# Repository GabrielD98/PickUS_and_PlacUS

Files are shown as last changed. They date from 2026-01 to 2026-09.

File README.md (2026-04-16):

# PickUS and PlacUS

A 4-axis (X, Y, Z, Yaw) PCB pick-and-place machine for automated SMD component assembly. Built for the S4 robotics project at Université de Sherbrooke.

## Table of Contents

1. [About](#about)
2. [Features](#features)
3. [Tech Stack](#tech-stack)
4. [Project Structure](#project-structure)
5. [Quick Start](#quick-start)
6. [Roadmap](#roadmap)
7. [Contributing](#contributing)
8. [License](#license)
9. [Contact](#contact)

---

## About

### Problem
Manual SMD component placement onto PCBs is time-consuming and error-prone. Small labs and educational institutions need an affordable pick-and-place machine for fast prototyping.

### Solution
PickUS and PlacUS is an open-source, 4-axis automated pick-and-place machine that:
- Picks SMD components using a vacuum pump system
- Places them onto PCBs with positional accuracy
- Uses stepper motors for precise X, Y, Z, and rotational (Yaw) control
- Integrates with KiCad placement files for automated workflows

### Audience
Ideal for robotics project teams, PCB assembly labs, and makers who need to automate component placement without high capital investment.

---

## Features

- **4-Axis Control**: X, Y, Z positioning + Yaw rotation for flexible placement
- **Vacuum Pick System**: Pneumatic pump and valve for reliable component pickup
- **Pressure Sensing**: Real-time feedback to detect successful component pickup
- **End-Stop Protection**: Z-axis limit switch to prevent collision damage
- **ESP32-S3 Controller**: Over-the-air updateable firmware with multiple I/O options
- **Python HMI**: Cross-platform graphical interface for machine control
- **KiCad Integration**: Direct import of `.pos` placement files for batch production
- **Modular Design**: Separate electrical, firmware, and HMI components

---

## Tech Stack

| Component | Technology |
|---|---|
| Microcontroller | ESP32-S3 (32-bit, dual-core, 240 MHz) |
| Motor Control | Stepper drivers (NEMA-17 steppers on X,Y,Z and NEMA_8 on YAW) |
| Firmware | C++ with PlatformIO / Arduino framework |
| Motor Library | [AccelStepper](https://github.com/waspinator/AccelStepper) |
| Communication | UART (serial) at 115200 baud |
| HMI | Python 3 + PyQt5/PySimpleGUI |
| Serial Library | `pyserial` |
| PCB Design | KiCad 8+ |
| Schematic | `circuitPNP/` main board + `PCB_test/` test board |

---

## Project Structure

```
PickUS_and_PlacUS/
├── Electrical/              # KiCad schematics and PCB layouts
│   ├── PNP_MOBO_V1/         # Main control board
│   ├── PNP_TEST_CIRCUIT_V1/ # Test board for validation
│   └── README.md            # Electrical recreation guide
├── Firmware_esp32/          # ESP32-S3 firmware (PlatformIO)
│   ├── src/                 # C++ source files
│   ├── lib/                 # Libraries (AccelStepper, etc.)
│   ├── test/                # Unit tests
│   ├── include/             # Header files
│   └── platformio.ini       # PlatformIO config
└── HMI/                     # Python host interface
    ├── src/                 # Main HMI modules
    │   ├── gui/             # GUI components
    │   ├── communication.py # Serial protocol
    │   ├── controller.py    # Command orchestration
    │   ├── main.py          # Entry point
    │   └── ...
    └── tests/               # Unit and integration tests
```

---

## Quick Start

Each subsystem has its own detailed README:

- **[Firmware_esp32/](Firmware_esp32/)** — ESP32-S3 firmware setup and configuration
- **[HMI/](HMI/)** — Python host interface installation and usage
- **[Electrical/](Electrical/)** — PCB design and electrical recreation guide
- **[Mechanical/](Mechanical/)** — Mechanical recreation guide, BOM, and STL

---

## Getting Started

### For Developers

1. Clone this repository
2. Navigate to the subsystem folder of interest (Firmware, HMI, or Electrical)
3. Follow the README in that folder for detailed setup instructions

### Project Overview

| Subsystem | Technology | Purpose |
|---|---|---|
| **Firmware_esp32** | C++ with PlatformIO | Real-time motor control, sensor reading, and command execution |
| **HMI** | Python 3 + PyQt5 | Cross-platform UI for machine operation and KiCad file import |
| **Electrical** | KiCad 8+ | Circuit design and PCB layouts |

---

## Roadmap

- [ ] Multi-head support for parallel placement
- [ ] Vision-based component alignment
- [ ] Auto feeder implementation
- [ ] Machine learning for optimal pick order optimization

---

## License

This project uses a split-license model:

- **Software (firmware + HMI source code)**: MIT License ([LICENSE](LICENSE))
- **Hardware design files** (schematics, PCB layouts, fabrication files): CERN Open Hardware Licence v2 - Permissive ([LICENSE-HARDWARE](LICENSE-HARDWARE))

---

## Acknowledgments

- [PlatformIO](https://platformio.org/) for embedded development tools
- [KiCad](https://www.kicad.org/) for PCB design
- [AccelStepper Library](https://www.airspayce.com/mikem/arduino/AccelStepper/) for motor control
- Université de Sherbrooke robotics program
- All contributors and testers

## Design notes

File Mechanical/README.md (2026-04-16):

# Mechanical instructions

The Pick and place is built in a specific way with complex pieces, to insure a good functionning device, please follow the instructions provided.

## Bill of Material

The project is made with pieces and component purchased on the internet. Including alluminum extrusion, gears, belts, rails and motors. But a big part of the project can be 3d printed and laser cutted. 

### Pieces to Print or Laser cut

All the STL files needed are provided in the Mechanical folder in a folder named STL_Files. We recommend to print all the pieces before starting the assembly, but the pieces needed in each instruction will be cited so can be printed in order. All the pieces are printed with PLA for reduced costs.

There is also a MakerWord project created with all the pieces ready to print. https://makerworld.com/en/models/2670527-pickus-and-plackus#profileId-2955730

The base plate is laser cutted for a size reason and is made of wood.

### Pieces to Buy

All the pieces or component to buy are in the Mechanical folder named BOM. The Bill of Material contain all the pieces needed to complete de Project with links to the websites. Please note that the product were purchased and delivered in Canada so some of the links may not work or be discontinued.

The pieces were bought principally on Amazon.ca and Aliexpress.com. 

## Instructions

The complete assembly is provided in the STL_Files folder to guide you during the assembly process.

### Step 1 : Base

#### Pieces needed: 
1. Alluminum extrusion 7x
#### Print Needed:
1. FootMountSS-BackRight.stl
2. FootMountSS-FrontRight.stl
3. FootMountSS-BackLeft.stl
4. FootMountSS-FrontLeft.stl
5. 90DegreesJoint.stl 2x
6. BasePlateSupport.stl (Laser Cutted)
7. BasePlate.stl (Laser Cutted)

Please Note: Always place the T-nuts needed in the extrusions before assembling.

First, Install the two 90 degrees joint in the middle of two alluminum extrusions. These will be on the front and back. Then, build a square with the four foot mounts, make sure to place them at the right place. Place the fifth extrusion in the middle and install the BasePlateSupport. Secure it in the four corners and then place the two remaining extrusions on the two sides. 

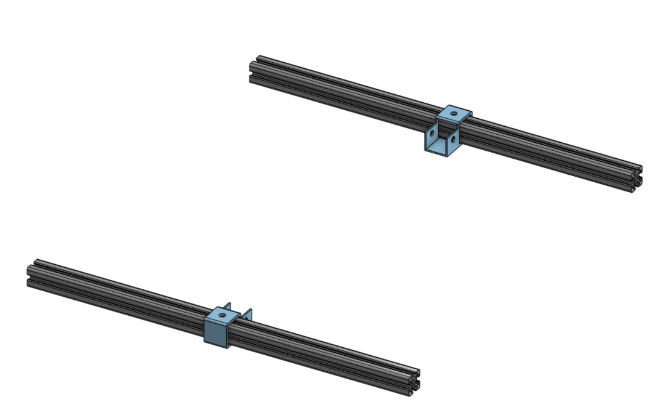
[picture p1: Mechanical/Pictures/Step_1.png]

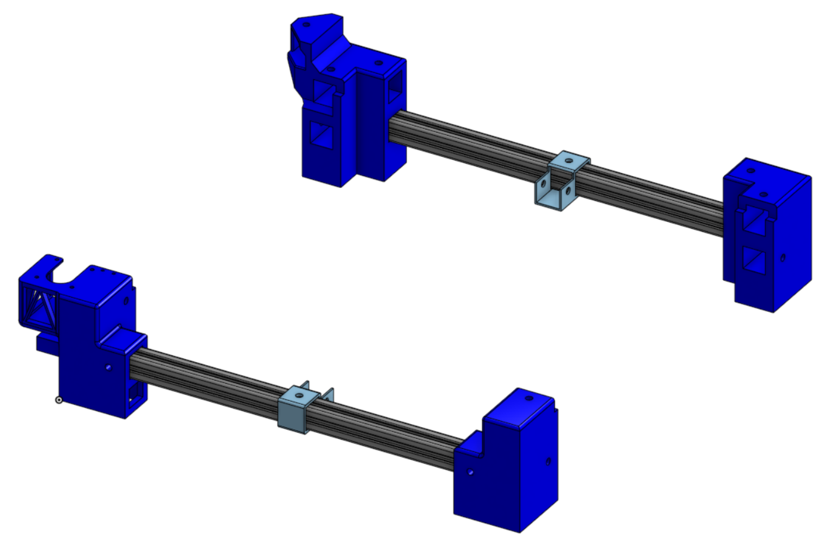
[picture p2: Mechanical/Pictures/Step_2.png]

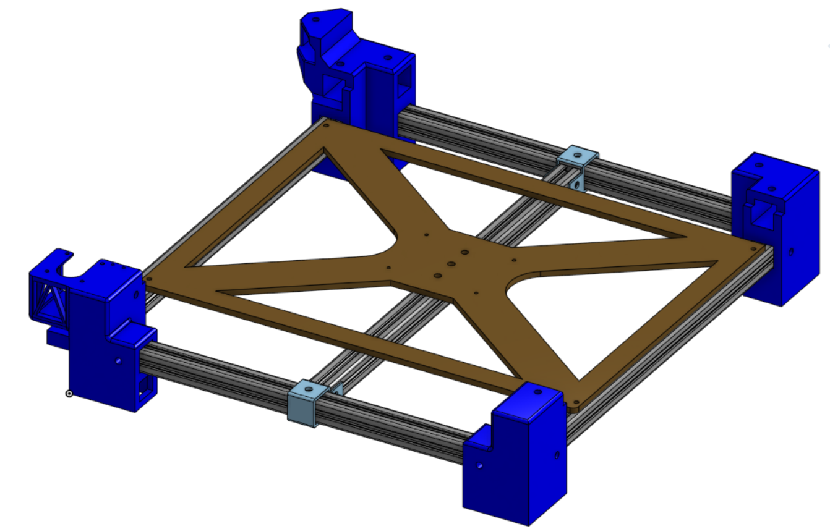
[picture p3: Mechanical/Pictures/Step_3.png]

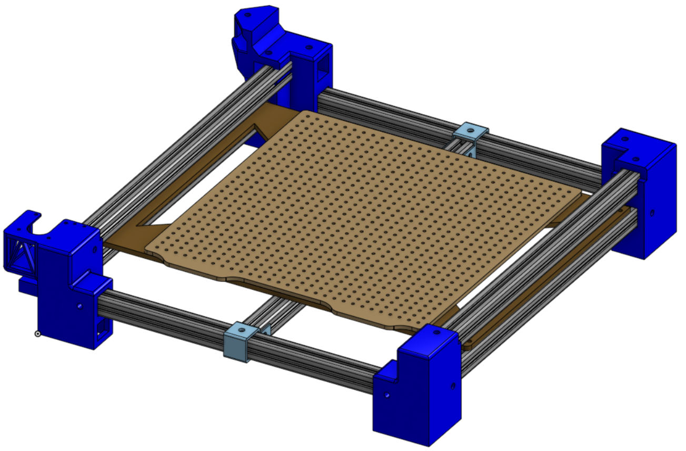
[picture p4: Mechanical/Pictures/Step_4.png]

---
### Step 2 : Y Movement

#### Pieces needed: 
1. Linear rails 2x
2. Gear 2x
3. Timing belt
4. Timing Belt Fixing Piece
5. Heat insert M4
6. Nema 17 motor
#### Print Needed:
1. Adaptor_RailY_Extrude_Inferior.stl 2x

Install the two rails with M3 bolts and Tnuts on the top extrusions. Place a heat insert in one of the printed piece and fix it to the moving cart on the left side, heat insert in the direction of the exterior of the device. Fix the other one on the opposite side. Place the gears, one on the motor, one with a M5 nut and bolt on the back left footmount. Cut the timing belt at the length needed, install on the gears but dont install now the motor. Put each extrimity of the belt on the fixing piece and then screw it in the heat insert. Now, install the motor in the front left foot mount. If the belt is too loose, you can cut it a little bit to have good belt tension. The gear on the motor must be scewed on the shaft and the other one left loose.

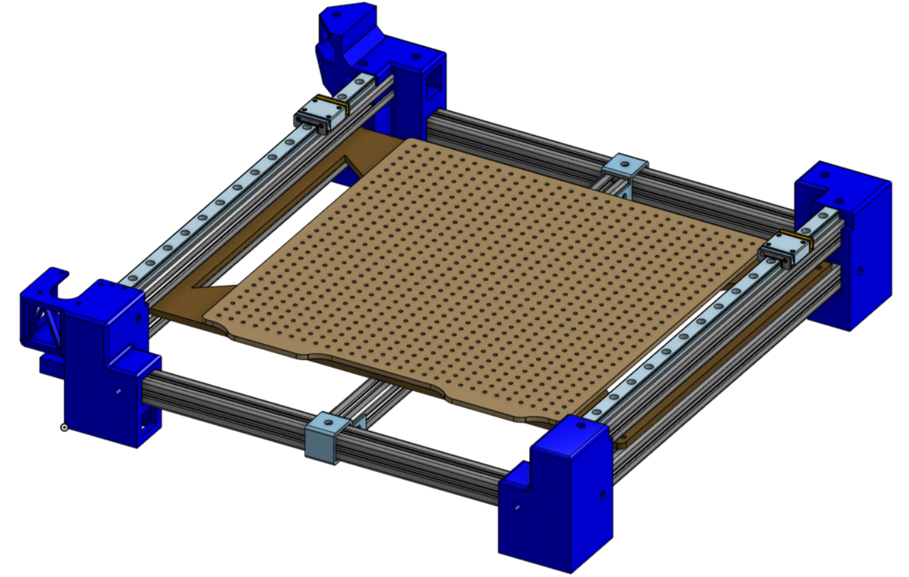
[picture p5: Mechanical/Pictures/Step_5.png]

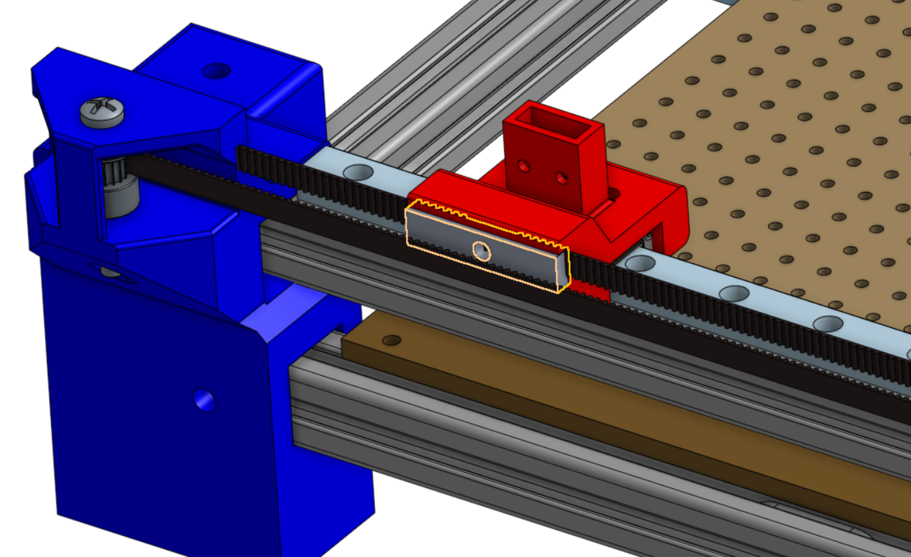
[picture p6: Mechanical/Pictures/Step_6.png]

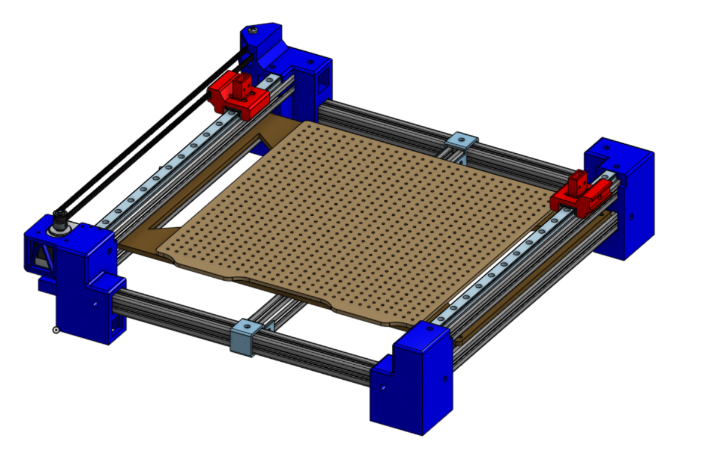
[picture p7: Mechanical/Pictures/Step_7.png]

---
### Step 3 : X Movement

#### Pieces needed: 
1. Linear rails 1x
2. Gear 2x
3. Timing belt
4. Timing Belt Fixing Piece
5. Heat insert M4
6. Nema 17 motor
7. alluminum extrusion
#### Print Needed:
1. Adaptor_RailY_Superior_Motor.stl
2. Adaptor_RailY_Extrude_Superior_Idle.stl
3. PnPHead.stl

Put the two complement on the rails. Big one on the motor side. Put a heat insert on the back of the PnP Head. Place the extrusion with a linear rail on the side facing the front. Screw the PnP head on the cart. Install the gears and timing belt as done in step 2 but install the motor first. 

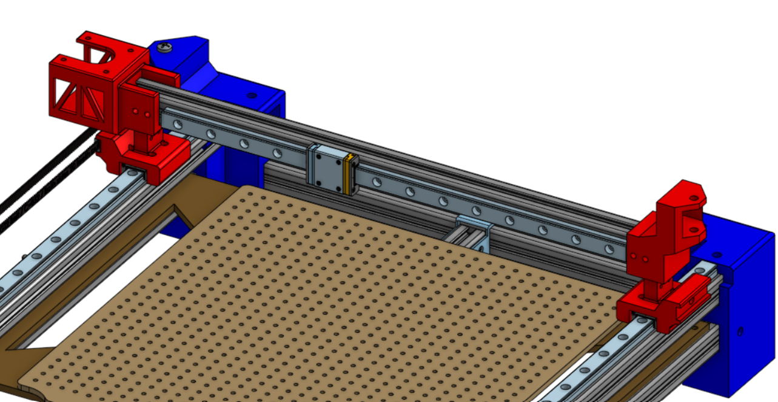
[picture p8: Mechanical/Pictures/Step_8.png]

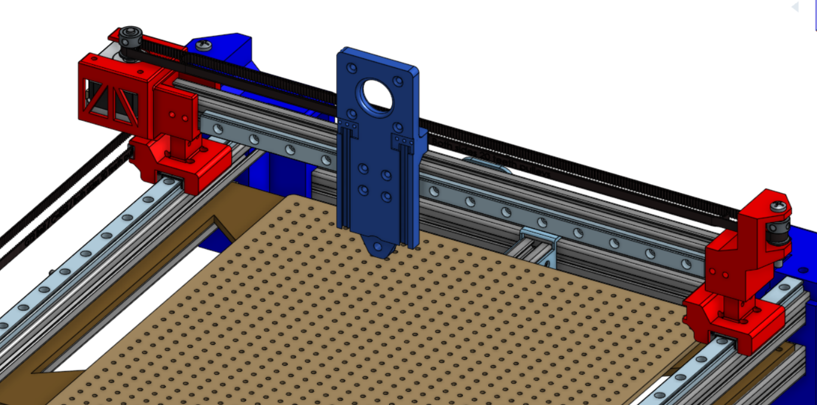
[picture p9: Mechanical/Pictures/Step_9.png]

---
### Step 4 : Z Movement and yaw

#### Pieces needed: 
1. Gear 2x
2. Timing belt
3. Timing Belt Fixing Piece
4. Heat insert M4
5. Nema 17 motor (small)
6. Nema 8 motor + toolhead
#### Print Needed:
1. PnPPicker.stl

Put a heat insert on the hole on the side of the PnP Picker piece. Install the Nema 8 motor and nozzle on the PnP Picker piece. Install the small Nema 17 motor on top of the PnP Head. Insert the Picker into the Head left rail. Then, install the gears and timing belt. 

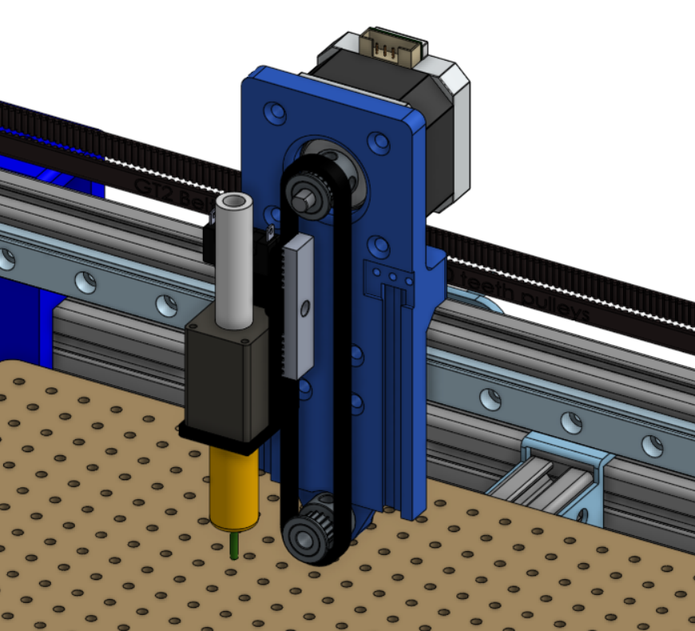
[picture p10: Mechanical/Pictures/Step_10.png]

---
### Step 5 : Limit Switch, cable management, cable chain and (electric box (peut être dans une autre étape))

#### Pieces needed: 
1. Heat insert M4 x4
2. Cables
3. Limit Switch x3
4. Electric components
#### Print Needed:
1. Chain_Adaptor_1.stl
2. Chain_adaptor_2.stl
3. Chain_Adaptor_3.stl
4. Chain_Adaptor_4.stl
5. Chain_Link.stl x25
6. Chain_Cover.stl x 20
7. Chain_Support_TRail_YAxis.stl x3
8. Electric_Box.stl

It is now time to put all the cables and the XYZ limit switches. Make sure to cut long enough wires for it to pass trough the cable chains (if you want to install some). You can put all the electrics (PCB, Vacuum, drives) in the electric box underneath the PnP. 

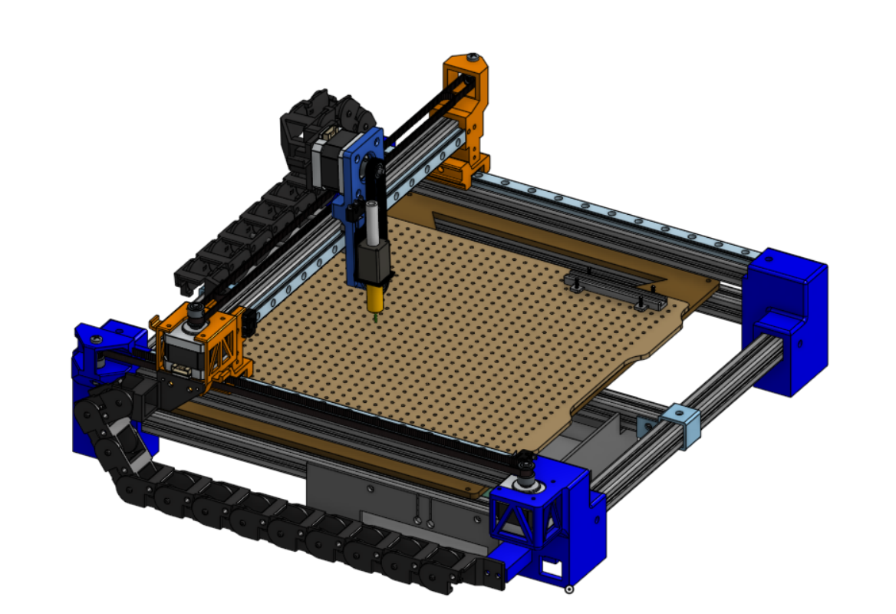
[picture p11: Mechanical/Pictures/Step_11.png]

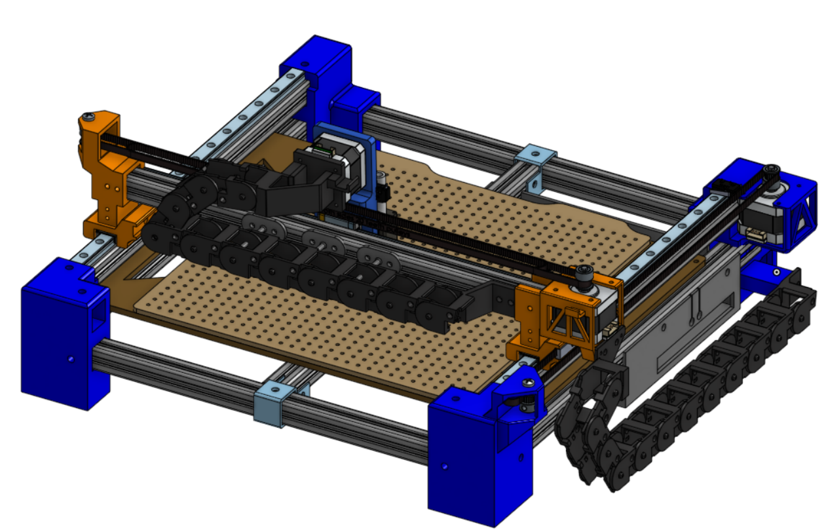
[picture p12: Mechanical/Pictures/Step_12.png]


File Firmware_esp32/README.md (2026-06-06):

# Firmware (ESP32-S3)

Firmware for motor control, sensor reading, and command execution on the PickUS and PlacUS machine.

## Prerequisites

- [PlatformIO](https://platformio.org/) (VS Code extension recommended)
- ESP32-S3 DevKitC-1 board
- USB-to-Serial cable for flashing

## Installation

1. **Install PlatformIO**
   - Open VS Code and install the PlatformIO extension

2. **Open the project**
   ```bash
   cd Firmware_esp32
   ```

3. **Build and upload**
   ```bash
   pio run --target upload
   ```

4. **Monitor serial output** (115200 baud)
   ```bash
   pio device monitor
   ```

---

## Configuration

### Pin Mapping (`boardconfig.h`)

| Signal | Pin | Direction |
|---|-----|---|
| Motor X DIR/STEP/EN | 6 / 7 / 15 | Output |
| Motor Y DIR/STEP/EN | 16 / 17 / 18 | Output |
| Motor Z DIR/STEP/EN | 3 / 46 / 11 | Output |
| Motor YAW DIR/STEP/EN | 12 / 13 / 14 | Output |
| Vacuum pump | 5 | Output |
| Valve | 4 | Output |
| Limit switch X | 35 | Input |
| Limit switch Y | 36 | Input |
| Limit switch Z | 37 | Input |
| Pressure sensor CLK/DATA | 2 / 1 | I/O |
| CAN TX/RX | 47 / 48 | I/O |

### Serial Communication

- **Baud Rate**: 115200
- **Protocol**: Command-based (see Command IDs below)
- **Flow Control**: None

---

## Usage

### Firmware Overview

The firmware consists of these key modules:

| Module | File | Responsibility |
|---|---|---|
| `Controller` | `controller.h/cpp` | Coordinates command handling, motion, homing, pick/place sequences, and machine state updates |
| `DataModel` | `datamodel.h/cpp` | Thread-safe shared command/position/state buffer between the controller and the communication task |
| `Communication` | `main.cpp` | UART protocol that receives `command_t` packets and sends back `statusFrame_t` replies |
| `Geometry` | `geometry.h/cpp` | Converts between cartesian coordinates and motor steps / velocities |
| `Mosfet` | `mosfet.h/cpp` | Controls the vacuum pump and valve outputs |
| `Pressure Sensor` | `pressuresensor.h/cpp` | Reads and converts the bit-banged pressure sensor signal into kPa |
| `Limit Switch` | `limitswitch.h/cpp` | Monitors X, Y, Z end-stops for homing and safety |

### Command IDs

| Command | Value | Description | Parameters |
|---|---|---|---|
| `STOP` | 0 | Stop all motors | None |
| `MOVE` | 1 | Move to position at velocity | x, y, z, yaw, velocity |
| `PICK` | 2 | Pick sequence (lower Z, activate pump) | None |
| `PLACE` | 3 | Place sequence (activate valve) | None |
| `HOME` | 4 | Run homing sequence | None |
| `EMPTY` | 5 | No-op / idle | None |

### Machine States

| State | Description |
|---|---|
| `READY` | Idle, waiting for a command |
| `MOVING` | Executing a MOVE command |
| `PICKING` | Executing a PICK sequence |
| `PLACING` | Executing a PLACE sequence |
| `HOMING` | Executing the homing sequence |
| `ERROR` | Fault condition detected |

---

## Testing

### Run Unit Tests

The firmware includes test hooks controlled by `platformio.ini` build flags:

- `ENABLE_TEST=1` runs the internal test task instead of normal control/communication tasks.
- `ENABLE_COM_TEST=1` runs the communication test task alongside the test task.
- Both flags are set to `0` by default for normal firmware operation.

---

## Project Structure

```
Firmware_esp32/
├── src/                     # Firmware source files
│   ├── boardconfig.h
│   ├── controller.cpp/h
│   ├── datamodel.cpp/h
│   ├── geometry.cpp/h
│   ├── limitswitch.cpp/h
│   ├── main.cpp
│   ├── mosfet.cpp/h
│   ├── pressuresensor.cpp/h
│   └── tests/               # Internal test helpers and scenarios
├── lib/                     # Shared data types and external libraries
│   ├── data.hpp
│   └── AccelStepper/
├── include/                 # Header includes placeholder
├── output/                  # Generated build/output artifacts
├── test/                    # PlatformIO test entry point
│   └── README
├── platformio.ini           # PlatformIO configuration
└── README.md
```

---

## Dependencies

- [AccelStepper](https://github.com/waspinator/AccelStepper) (`waspinator/AccelStepper@^1.64`) — stepper motor control

---

## Troubleshooting

### Serial Monitor Not Connecting
- Verify USB cable is connected
- Check Device Manager (Windows) or `/dev/ttyUSB*` (Linux) for the correct COM port
- Ensure baud rate is set to 115200

### Build Fails
- Clean the build: `pio run --target clean`
- Check that all libraries are installed and up to date

---

## Next Steps

- See [main README](../README.md) for project overview
- See [HMI README](../HMI/) for host interface setup
- See [Electrical README](../Electrical/) for hardware design
- See [Mechanical README](../Mechanical/) for mechanical design

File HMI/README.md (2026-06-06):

# HMI (Python Host Interface)

Cross-platform graphical interface for controlling the PickUS and PlacUS machine. Communicate with the ESP32 firmware over USB serial, import KiCad placement files, and orchestrate pick-and-place operations.

## Prerequisites

- Python 3.8 or higher
- `pip` package manager
- USB connection to ESP32-S3 board

## Installation

1. **Install dependencies**
   ```bash
   pip install pyserial
   ```

2. **Navigate to HMI source folder**
   ```bash
   cd HMI/src
   ```

3. **Run the HMI**
   ```bash
   python main.py
   ```

---

## Configuration

### Serial Port Settings

To find your port:
- **Windows**: Device Manager → Ports (COM & LPT)
- **Linux**: Run `ls /dev/ttyUSB*`
- **macOS**: Run `ls /dev/tty.usbserial*`

---

## Usage

### Typical Workflow

1. Launch the HMI: `python main.py`
2. Load a KiCad `.pos` file via the GUI
3. Home the machine to access manual mode
4. Configure component feeders for each tray
   1. Fill all of the required fields in the displayed window
   2. Place the tip of the gripper on the first piece of the storage
   3. Confirm to save the data 
5. Calibrate PCB position
   1. place the tip of the gripper on the calibration point of the PCB (has to be set by the user in KiCad)
   2. Confirm to save the data 
6. Generate commands by clicking the slice button
5. Start the pick-and-place cycle
6. Monitor progress and pause/resume as needed

### HMI Module Overview

| Module | Responsibility |
|---|---|
| `Controller` | Manages state, command queue, and background control loop |
| `CommandDispatcher` | Queues commands and serializes them for transport |
| `PnPStateMachine` | Resolves controller state transitions and next commands |
| `MachineTelemetryDecoder` | Decodes telemetry packets from the ESP32 |
| `HomingService` | Runs the homing workflow in a background thread |
| `Communication` | Low-level UART wrapper around `pyserial` |
| `FileInterpreter` | Parses KiCad `.pos` placement files into `Piece` objects |
| `Slicer` | Generates ordered `Command` sequence: pick → move → place per component |
| `Storage` | Tracks available components in feeder trays |

---

## Testing

### Run All Tests

```bash
cd HMI/tests
python run_test.py
```

### Individual Test Files

- `test_controller_communication.py` — Serial protocol tests
- `test_file_interpreter.py` — KiCad `.pos` file parsing
- `test_slicer.py` — Command sequence generation
- `test_storage.py` — Feeder tray logic

Each test file can be run independently:

```bash
python test_file_interpreter.py
```

---

## Project Structure

```
HMI/
├── src/                     # Main HMI modules
│   ├── main.py              # Entry point
│   ├── communication.py      # Serial protocol
│   ├── controller.py         # Command orchestration
│   ├── command_dispatcher.py # Controller command queue management
│   ├── data.py              # Data models
│   ├── file_interpreter.py  # KiCad .pos parser
│   ├── homing_service.py    # Homing workflow
│   ├── machine_telemetry_decoder.py # Telemetry packet decoding
│   ├── slicer.py            # Command generation
│   ├── pnp_state_machine.py  # Controller state transitions
│   ├── storage.py           # Component inventory
│   ├── utils.py             # Utilities
│   └── gui/                 # GUI components
│       ├── interface.py
│       ├── command_widget.py
│       ├── jog_widget.py
│       ├── pnp_state_widget.py
│       └── ...
├── tests/                   # Unit and integration tests
│   ├── run_test.py          # Test runner
│   ├── test_*.py            # Individual test modules
│   └── data/                # Test data files
├── data/                    # Sample data files
└── README.md
```

---

## Class Diagram
### Main project UML
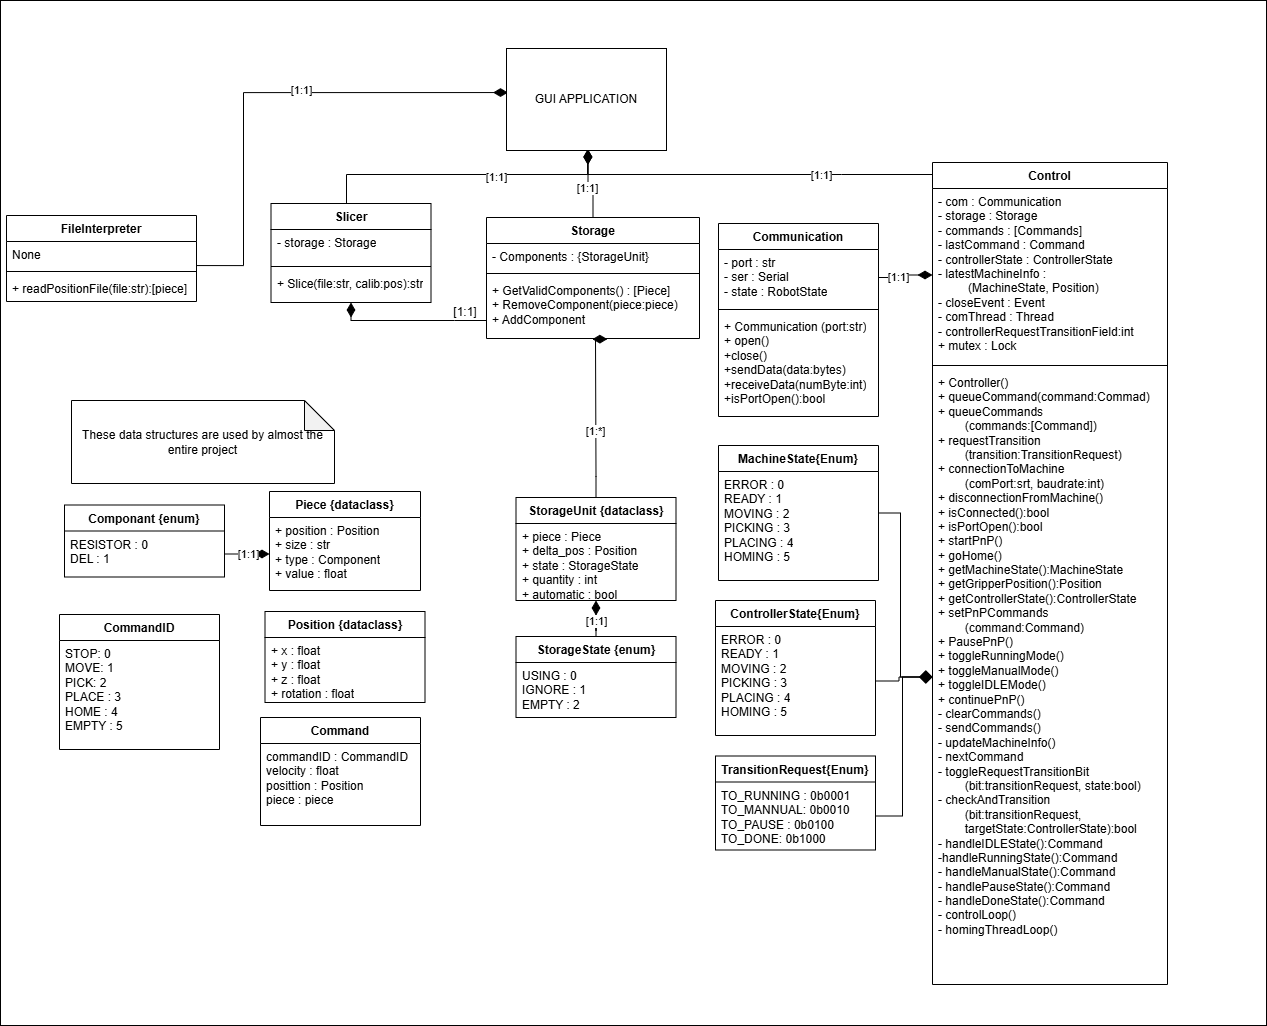
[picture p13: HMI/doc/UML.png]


### GUI UML
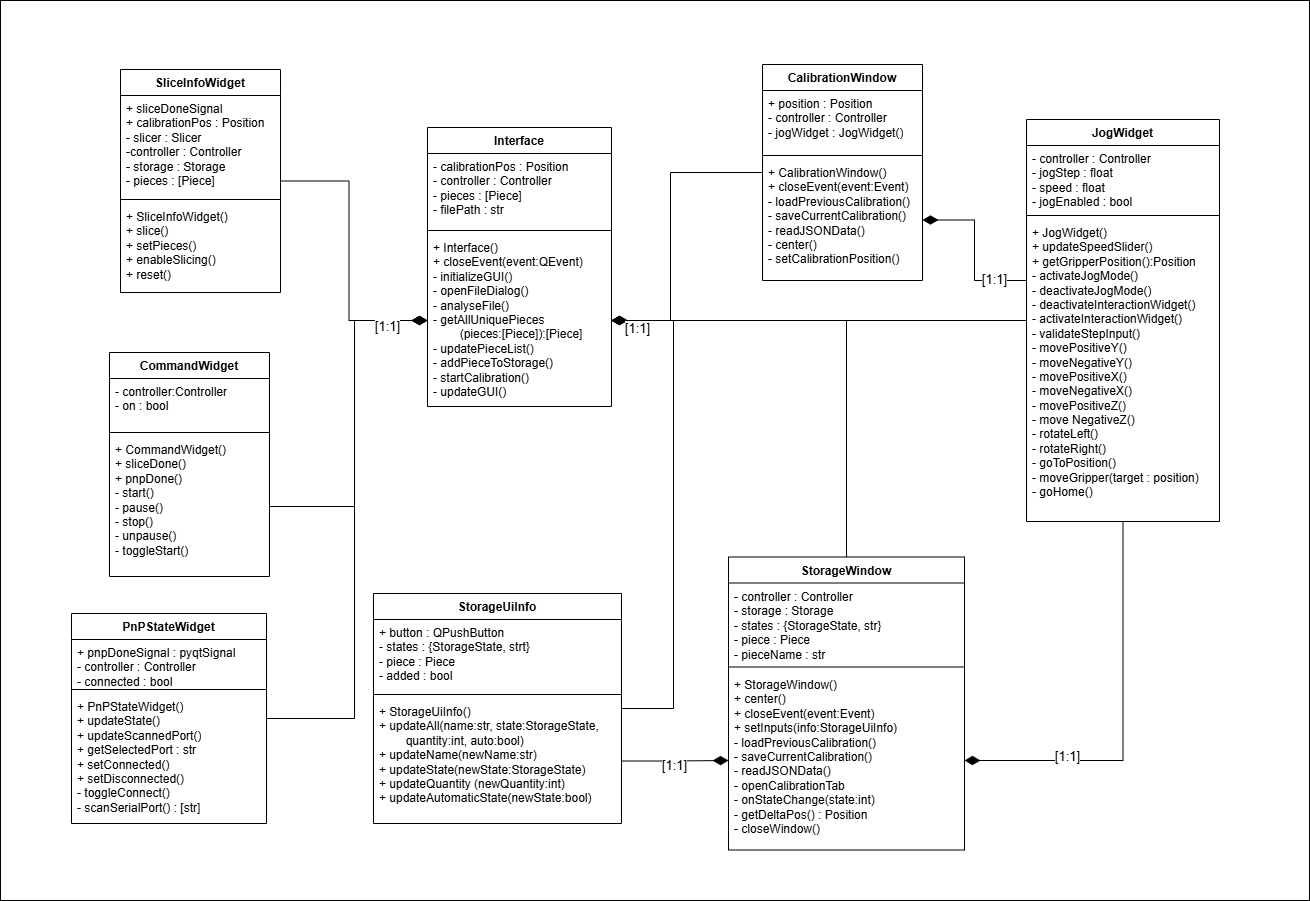
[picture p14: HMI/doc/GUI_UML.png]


---

## Dependencies

- `pyserial` — serial communication with ESP32

---

## Troubleshooting

### Cannot Connect to Serial Port
- Verify the ESP32 is plugged in and connected
- Check Device Manager for the correct COM port
- Ensure no other application is using the port
- Try unplugging and replugging the USB cable

### FileNotFoundError: Cannot find .pos file
- Ensure the full path to the KiCad placement file is correct
- Verify the file exists and is readable

### Commands Not Executing
- Check that the ESP32 firmware is running and responsive
- Open serial monitor to verify communication: `pio device monitor` (in Firmware_esp32 folder)
- Verify baud rate matches (115200)

---

## Next Steps

- See [main README](../README.md) for project overview
- See [Firmware README](../Firmware_esp32/) for ESP32 setup and configuration
- See [Electrical README](../Electrical/) for hardware design
- See [Mechanical README](../Mechanical/) for mechanical design

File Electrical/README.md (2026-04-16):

# Electrical Guide

PCB design and schematics for the PickUS and PlacUS machine. Includes main control board and test board for validation.

## Scope

The electrical work is split into two KiCad projects:

- `PNP_MOBO_V1/` — Main control board for the machine
- `PNP_TEST_CIRCUIT_V1/` — Test board for validating pick and place operation

## Prerequisites

- KiCad 8 (recommended)
- Basic soldering tools and bench power supply for bring-up
- Optional for production:
  - PCB manufacturer account (JLCPCB, PCBWay, etc.)
  - Assembly service for SMT components

---

## Installation & Setup

1. **Install KiCad**
   - Download from [https://www.kicad.org/](https://www.kicad.org/)
   - Install version 8 or later

2. **Open a project**
   ```bash
   cd Electrical/circuitPNP
   ```
   Or for the test board:
   ```bash
   cd Electrical/PCB_test
   ```

3. **Open in KiCad**
   - Double-click the `.kicad_pro` file, or
   - Launch KiCad and open the project file

---

## Project Structure

```
Electrical/
├── PNP_MOBO_V1/
│   ├── PNP_MOBO_V1.kicad_sch      # Main board schematic
│   ├── PNP_MOBO_V1.kicad_pcb      # Main board PCB layout
│   ├── PNP_MOBO_V1.kicad_pro      # Project file
│   ├── fabricationFile.zip       # Gerber, drill, and BOM exports
│   └── bom/                      # Bill of materials
├── PNP_TEST_CIRCUIT_V1/
|   ├── STENCIL.3mf
│   ├── PNP_TEST_CIRCUIT_V1.kicad_sch        # Test board schematic
│   ├── PNP_TEST_CIRCUIT_V1.kicad_pcb        # Test board PCB layout
│   └── PNP_TEST_CIRCUIT_V1.kicad_pro        # Project file
└── README.md
```

---

## Main Board (`PNP_MOBO_V1`)

### Key Subsystems

- **ESP32 Control & Communication**: Control and USB serial lines
- **Stepper Driver Interfaces**: DIR/STEP/EN signals for X, Y, Z, YAW motors
- **Vacuum Pump & Valve Switching**: Power control for pickup system
- **Pressure Sensor Interface**: Two-wire clock+data interface (bit-banged): toggle clock, sensor outputs one data bit per pulse (used for grip detection)
- **End-Stop Connectors**: Limit switch inputs for X, Y, Z axes
- **Can/I2C Connectors**: Additional expansion headers

---

## Test Board (`PNP_TEST_CIRCUIT_V1`)

### Purpose

Validate the pick-and-place workflow with a dedicated test board featuring standard footprints.

---

## Bring-Up & Validation

Complete this checklist as you recreate each board:

- [ ] KiCad project opens without missing symbol/footprint errors
- [ ] ERC passes with no critical errors
- [ ] All connectors have clear pin naming in schematic and silkscreen
- [ ] DRC passes with no critical errors
- [ ] Gerber and drill files exported
- [ ] BOM exported and validated with available stock
- [ ] Board assembled and visually inspected
- [ ] Continuity test completed on power rails and critical nets
- [ ] First power-on done with current-limited supply (no shorts)
- [ ] ESP32 and peripherals communication validated via firmware
- [ ] Motors, pump/valve, and sensors verified functionally

---

## Versioning & Release

- Use a version tag in the board title block and filenames (e.g., `v1`, `v2`)
- Commit schematic and PCB changes together

---

## BOM Organization

Recommended workflow:

- **PCB parts:** use the KiCad interactive BOM export (`PNP_MOBO_V1/bom/ibom.html`)
- **All non-PCB parts (electrical + mechanical):** see [Mechanical BOM](../Mechanical)

## Fabrication Tools

- **For stencil generation:** we use [gerber_to_scad](https://github.com/kirberich/gerber_to_scad)
- **Purpose:** generate stencil or fabrication geometry from the PCB source files

---

## Troubleshooting

### Missing Symbols or Footprints
- Verify all library paths are configured in KiCad
- Check that custom symbols/footprints are in the project library directory

### ERC or DRC Errors
- Review each error and determine if it's a genuine violation or a false positive
- Suppress false positives only after verification

### Design Rule Violations
- Consult your PCB manufacturer's design rules for clearance, trace width, and via sizes
- Update KiCad design rules to match your manufacturer specifications

---

## Next Steps

- See [main README](../README.md) for project overview
- See [Firmware README](../Firmware_esp32/) for ESP32 setup and firmware details
- See [HMI README](../HMI/) for host interface setup
- See [Mechanical README](../Mechanical/) for mechanical design

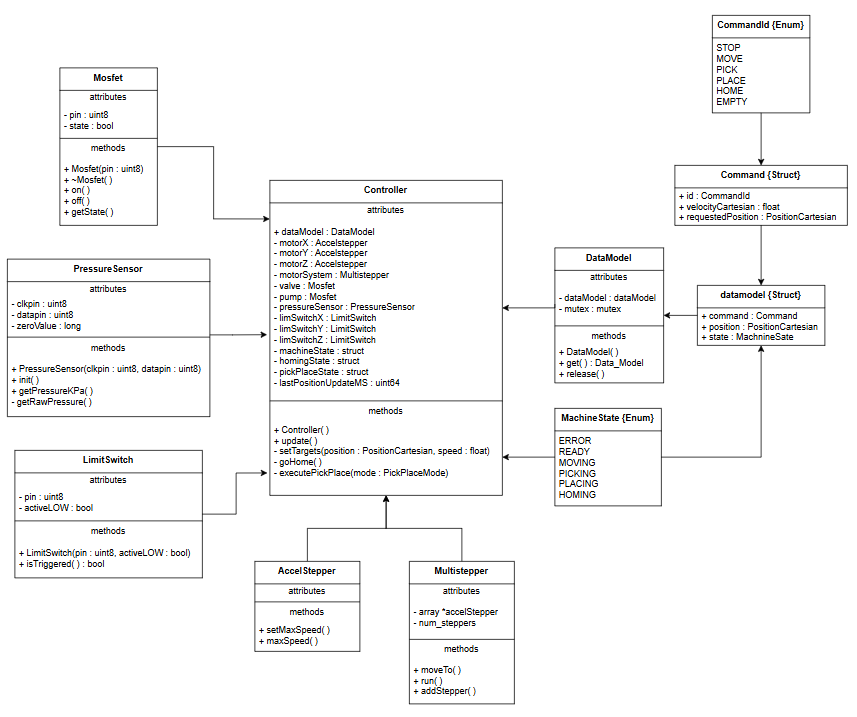
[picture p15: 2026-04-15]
Firmware_esp32/doc/ClassDiagram.png

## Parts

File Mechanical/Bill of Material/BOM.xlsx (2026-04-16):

Name | Quantity | Unitary price (CA$) | Description
17HS4023 NEMA 17 42x42x24mm 0.7A Bi-Polar Dual Phase 1.8° Stepper Motor | 1 | 21.92 | Z-axis motor | https://abra-electronics.com/electromechanical/motors/stepper-motors/nema-17/mot-17hs4023-17hs4023-nema-17-43mm-1.8a-dual-phase-stepper-motor-1.8.html
17HS3401 NEMA 17 42x42x34mm 1.3A Bi-Polar Dual Phase 1.8° Stepper Motor | 2 | 24.23 | X and Y-axis motors | https://a.co/d/0aSwmYSM
SMT head motor NEMA 8 with Nozzle and Air connector JUKI503 nozzle and KSH04-M5 | 1 | 59.07 | Yaw motor and nozzle | https://www.aliexpress.com/item/1005004594670502.html?mp=1
ESP32-S3 | 1 | 14.85 | Microcontroller | https://www.amazon.ca/ESP32-S3-core-board-N16R8-ESP32S3/dp/B0CB8MZKKB?mcid=05db73d0765e36c8a3a28b7daf04915a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
2/3Pin NO/NC Mini Limit Switch 5A 250VAC KW11-3Z-B | 3 | 0.35 | Limit switch | https://www.aliexpress.com/item/1005006085607858.html?curPageLogUid=sMc8UN0EK2FN
6 mm GT2 Pulley 20 Teeth 5mm bore | 6 | 1.74 | Belts gears | https://www.aliexpress.com/item/1005010636842055.html?mp=1
DC 12V Micro Vacuum Pump Mini 370 | 1 | 10.6 | Vacuum pump | https://a.co/d/05owCNzp
DC 3.3V 5V 0-40KPa Digital Barometric Air Pressure Module Connect 2.5mm Soft Tube | 1 | 2.74 | Pressure sensor | https://www.aliexpress.com/item/1005009068730991.html?curPageLogUid=HzYBfmJkU2Bq
DC 3V 3.7V 5V 2-way 2-position Small Mini Electric Solenoid Valve Normally Open | 1 | 4.33 | Solenoid valve | https://www.aliexpress.com/item/1005005779605656.html?mp=1
Miniature Linear Rail Slide With Carriage MGN9H 350 mm | 3 | 23.44 | Rail and sliding carriage | https://www.aliexpress.com/item/1005004908405311.html?mp=1
400mm T Slot 2020 Aluminum Extrusion European Standard Anodized Linear Rail | 8 | 7 | Aluminum Extrusion | https://www.amazon.ca/-/fr/lin%C3%A9aires-aluminium-europ%C3%A9enne-dimprimante-bricolage/dp/B0874387ZB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
Slide T Slot Nut for Aluminum Profile Accessories(European Standard 20-M4) | 29 | 0.25 | T slot nut | https://www.amazon.ca/Aluminum-Profile-Accessories-European-Standard/dp/B08B3RFK5W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
M4x6x6 Heat Set Brass Threaded Inserts | 7 | 0.16 | Heat insert | https://a.co/d/00AVqmbo
6mm GT2 Open Timing Belt Rubber Aramid Fiber, 1 m | 1 | 3.74 | Timing belt | https://www.aliexpress.com/item/10000401582873.html?mp=1
DRV8825 Stepper Motor Driver With Heat sink Carrier Reprap RAMPS 1.4 | 10 | 1.99 | Motor driver | https://www.aliexpress.com/item/1005006199405206.html?mp=1
GT2 Aluminum Block Timing Belt Fixing Piece Tooth Pitch 2mm Clamp 9 * 40mm | 3 | 2.1 | Timing belt fixation | https://www.amazon.ca/Printer-Aluminum-Timing-Fixing-Compatible/dp/B0B2LVK48W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
MP1584EN Adjustable 3A DC-DC Converter Step Down Voltage Regulator | 1 | 0.74 | DC-DC Converter | https://www.aliexpress.com/item/1005007653423578.html?curPageLogUid=qkn03UQ3FE2d
Pneumatic Tubing Polyurethane 4mm OD x 2.5mm ID, 5 m | 0.4 | 10.29 | Vaccum tubing | https://a.co/d/01etxmK3
3D printing PLA, 1 kg | 1 | 29.99 | Structure PLA | https://ca.store.bambulab.com/products/pla-basic-filament?id=43886297678064
M4 Hex Socket Head Cap Screw Bolts, various length |  |  | Bolt
M5 45 mm Hex Socket Head Cap Screw Bolts | 3 |  | Bolts for timing belt gears
5 mm Nut | 3 |  | Nuts for timing belt gears
molex 254 kk crimp
molex 254 kk 3pin male female
molex 254 kk 2pin male female
14 gauge awg electrical wire, 30 m | 1
 | Total | 372.94
*PS : Prices were given without taking taxes, shipping and discounts into account, from Canada, in April of 2026

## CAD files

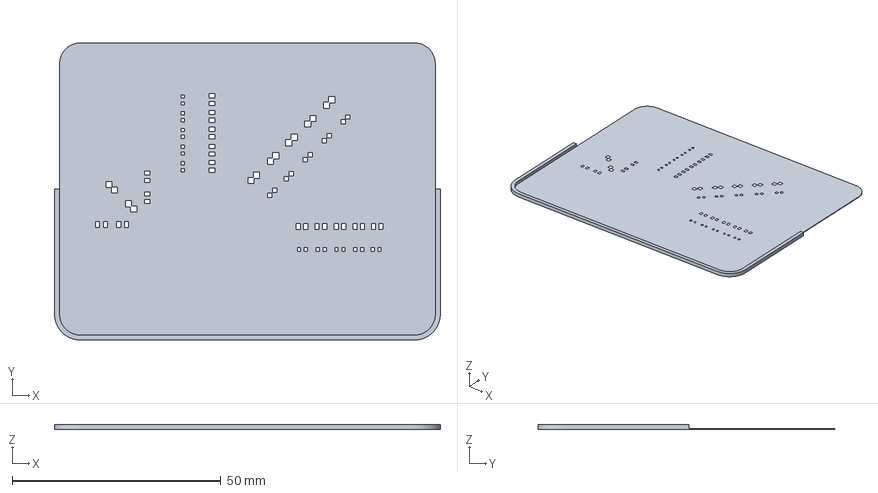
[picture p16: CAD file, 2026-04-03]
Electrical/PNP_TEST_CIRCUIT_V1/STENCIL.3mf
92.5 x 71.2 x 1.20 mm

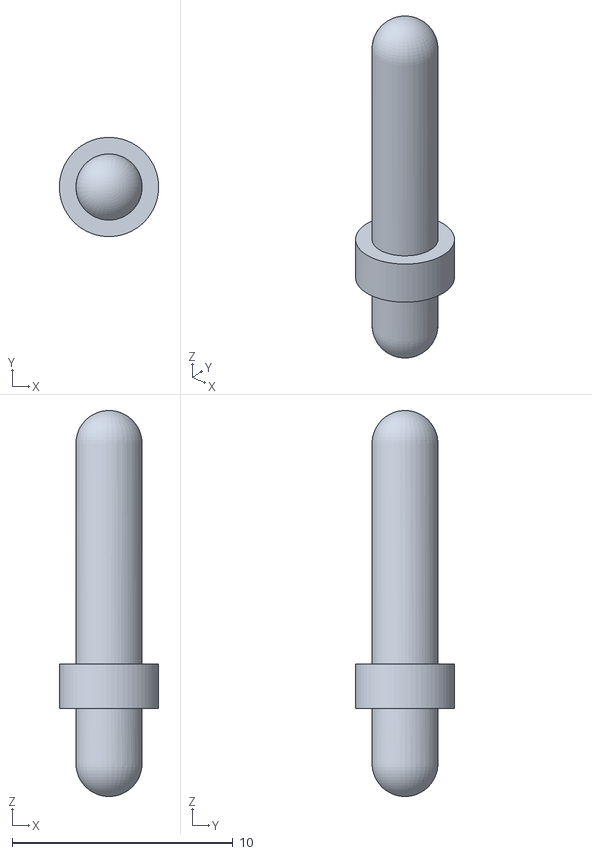
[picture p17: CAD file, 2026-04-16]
Mechanical/STL Files/Other/PressFit.stl
4.50 x 4.49 x 17.5

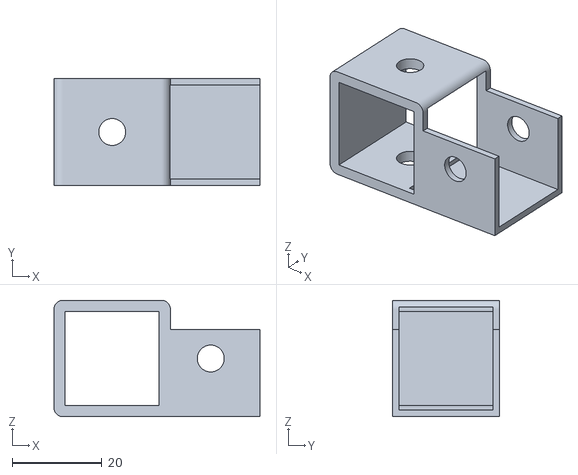
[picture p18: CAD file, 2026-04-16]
Mechanical/STL Files/Step 1/90DegreesJoint.stl
46.0 x 24.0 x 26.0

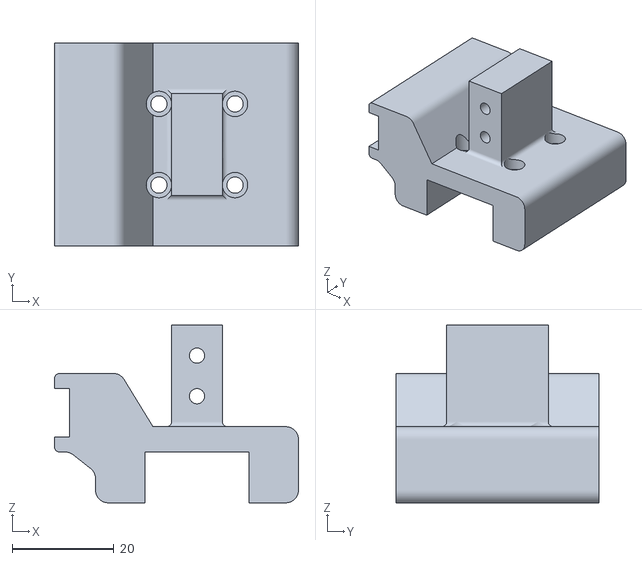
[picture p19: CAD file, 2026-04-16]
Mechanical/STL Files/Step 2/Adaptor_RailY_Extrude_Inferior.stl
48.1 x 40.0 x 35.0

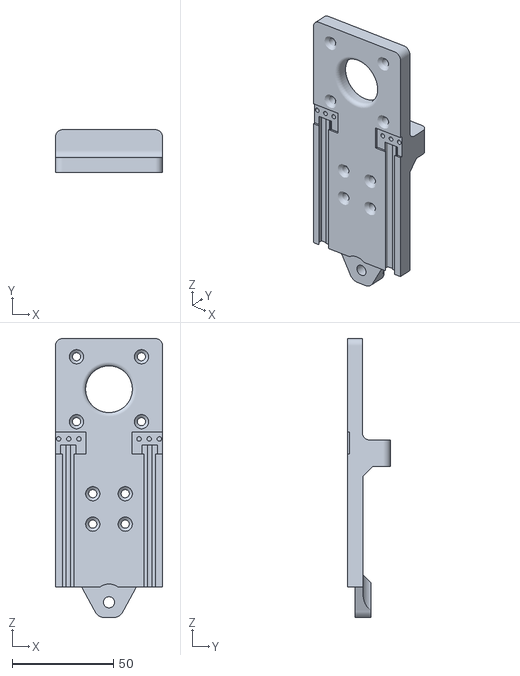
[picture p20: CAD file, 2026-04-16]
Mechanical/STL Files/Step 3/PnPHead.stl
52.8 x 21.0 x 137.5

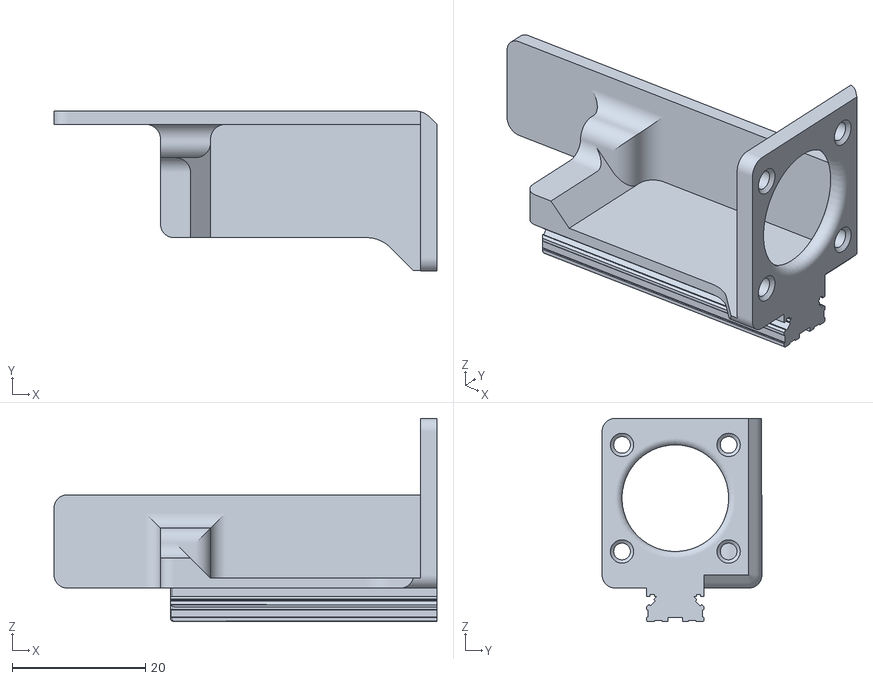
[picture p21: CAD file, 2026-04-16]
Mechanical/STL Files/Step 4/PnPPicker.stl
57.5 x 24.0 x 30.5

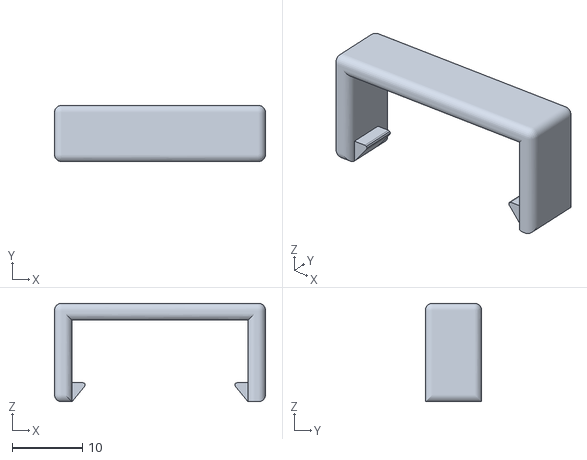
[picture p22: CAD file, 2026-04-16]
Mechanical/STL Files/Step 5/Chain_Cover.stl
30.0 x 8.00 x 14.0

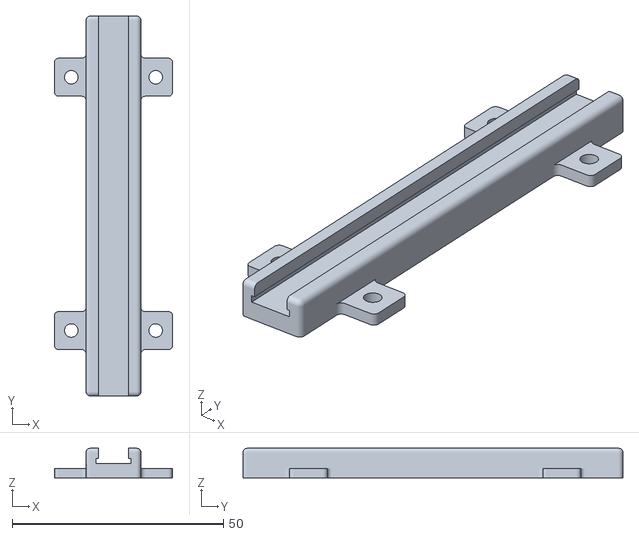
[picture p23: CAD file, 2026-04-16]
Mechanical/STL Files/Other/Storage_8mm(individual).stl
28.0 x 90.0 x 7.00

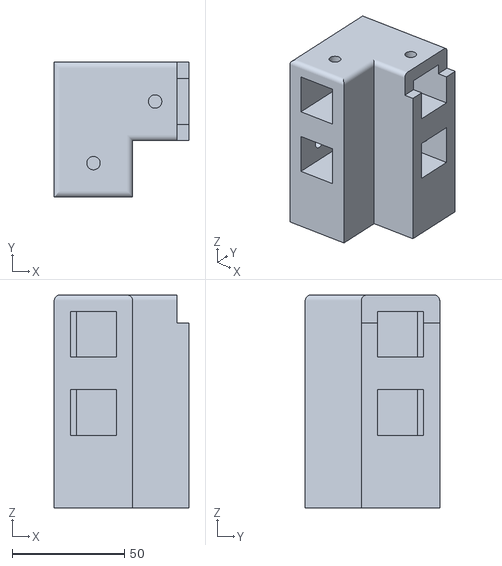
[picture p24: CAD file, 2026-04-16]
Mechanical/STL Files/Step 1/FootMountSS-BackRight.stl
60.0 x 60.0 x 95.0

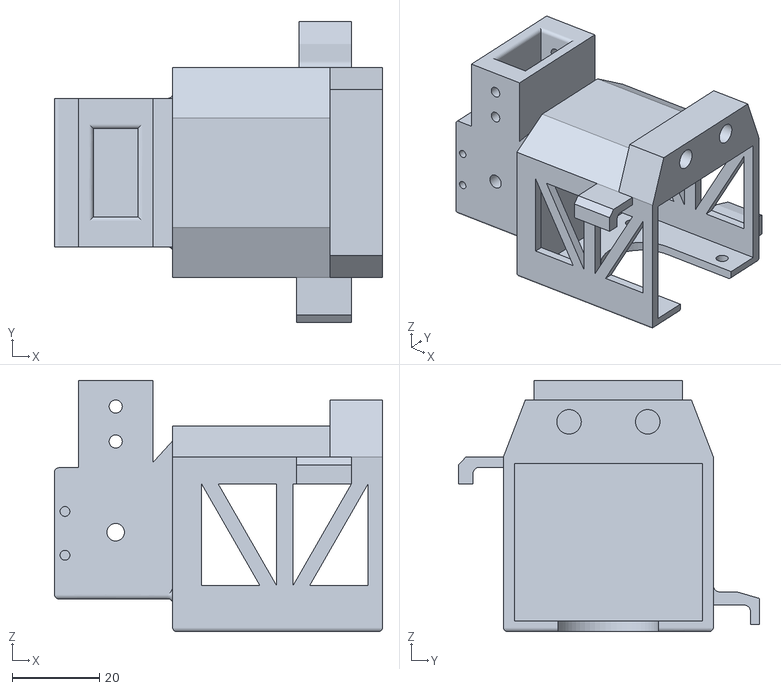
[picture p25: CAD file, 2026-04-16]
Mechanical/STL Files/Step 3/Adaptor_RailY_Superior_Motor.stl
75.0 x 68.9 x 57.5

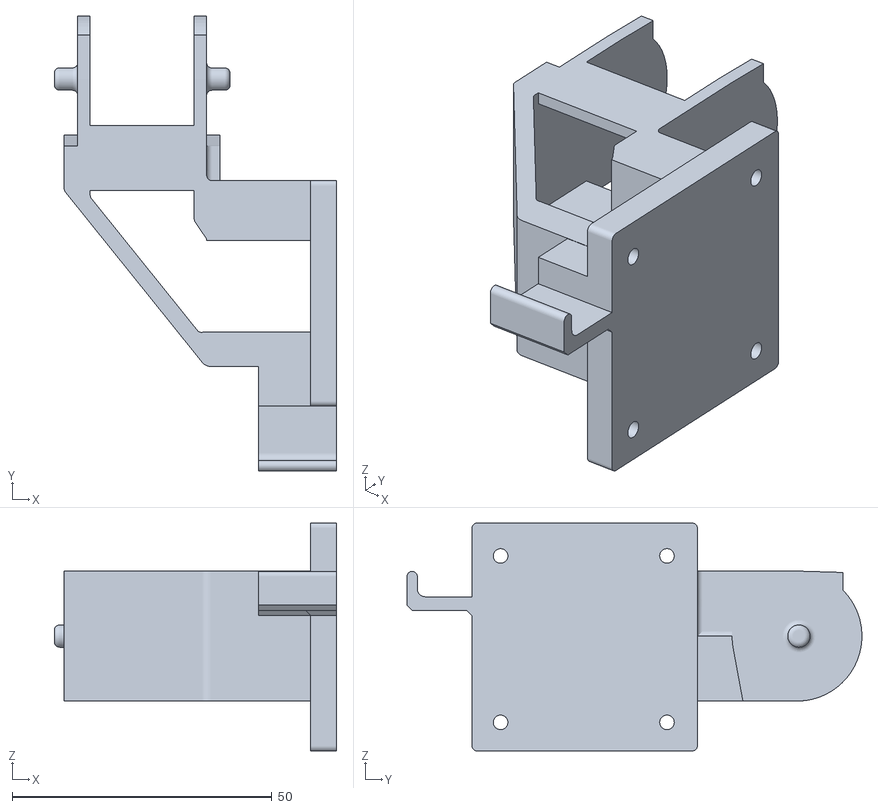
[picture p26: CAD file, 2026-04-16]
Mechanical/STL Files/Step 5/Chain_Adaptor_4.stl
54.3 x 87.5 x 43.8

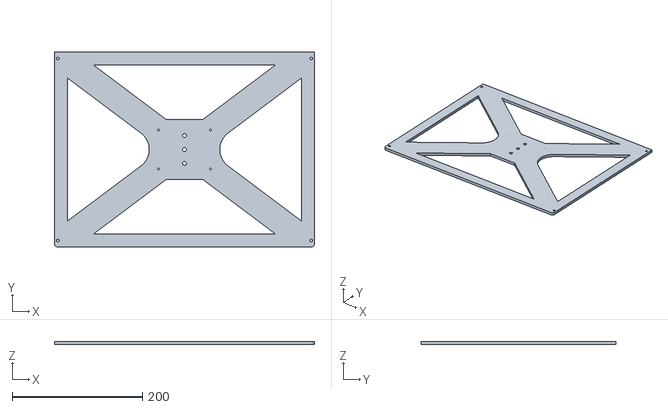
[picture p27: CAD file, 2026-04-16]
Mechanical/STL Files/Step 1/BasePlateSupport.stl
400.0 x 300.0 x 5.00

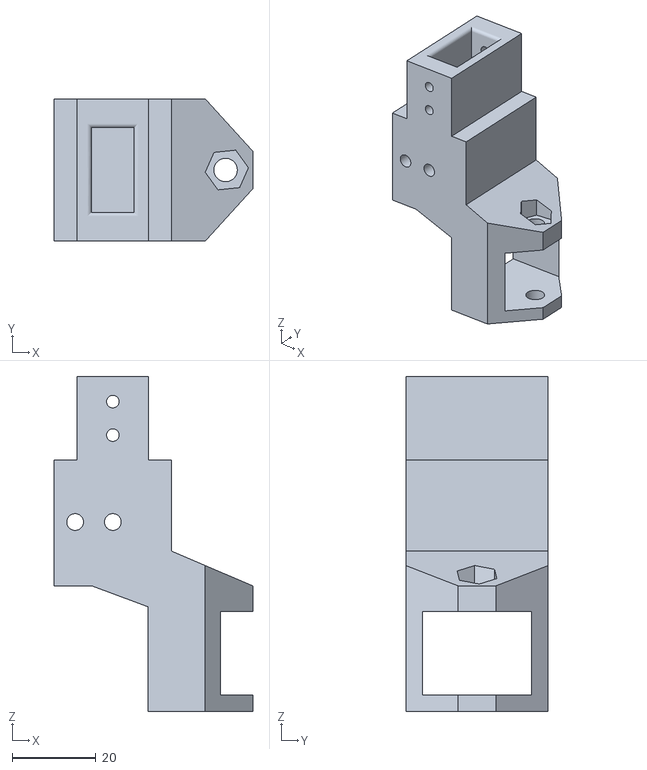
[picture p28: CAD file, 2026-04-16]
Mechanical/STL Files/Step 3/Adaptor_RailY_Extrude_Superior_Idle.stl
47.4 x 34.0 x 80.0

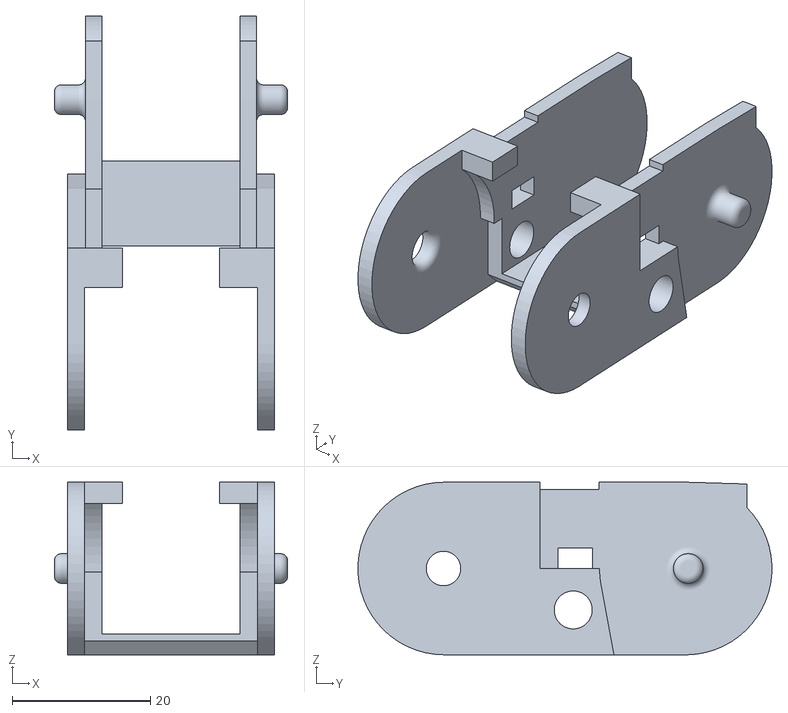
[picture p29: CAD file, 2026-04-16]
Mechanical/STL Files/Step 5/Chain_Link.stl
33.8 x 60.0 x 25.0

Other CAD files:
Mechanical/STL Files/Step 1/FootMountSS-BackLeft.stl
Mechanical/STL Files/Step 5/Chain_adaptor_2.stl
Mechanical/STL Files/Step 1/FootMountSS-FrontRight.stl
Mechanical/STL Files/Step 5/Electric_Box.stl
Mechanical/STL Files/Step 1/FootMountSS-FrontLeft.stl
Mechanical/STL Files/Step 5/Chain_Adaptor_1.stl
Mechanical/STL Files/Step 5/Chain_Adaptor_3.stl
Mechanical/STL Files/Step 5/Chain_Support_TRail_YAxis.stl

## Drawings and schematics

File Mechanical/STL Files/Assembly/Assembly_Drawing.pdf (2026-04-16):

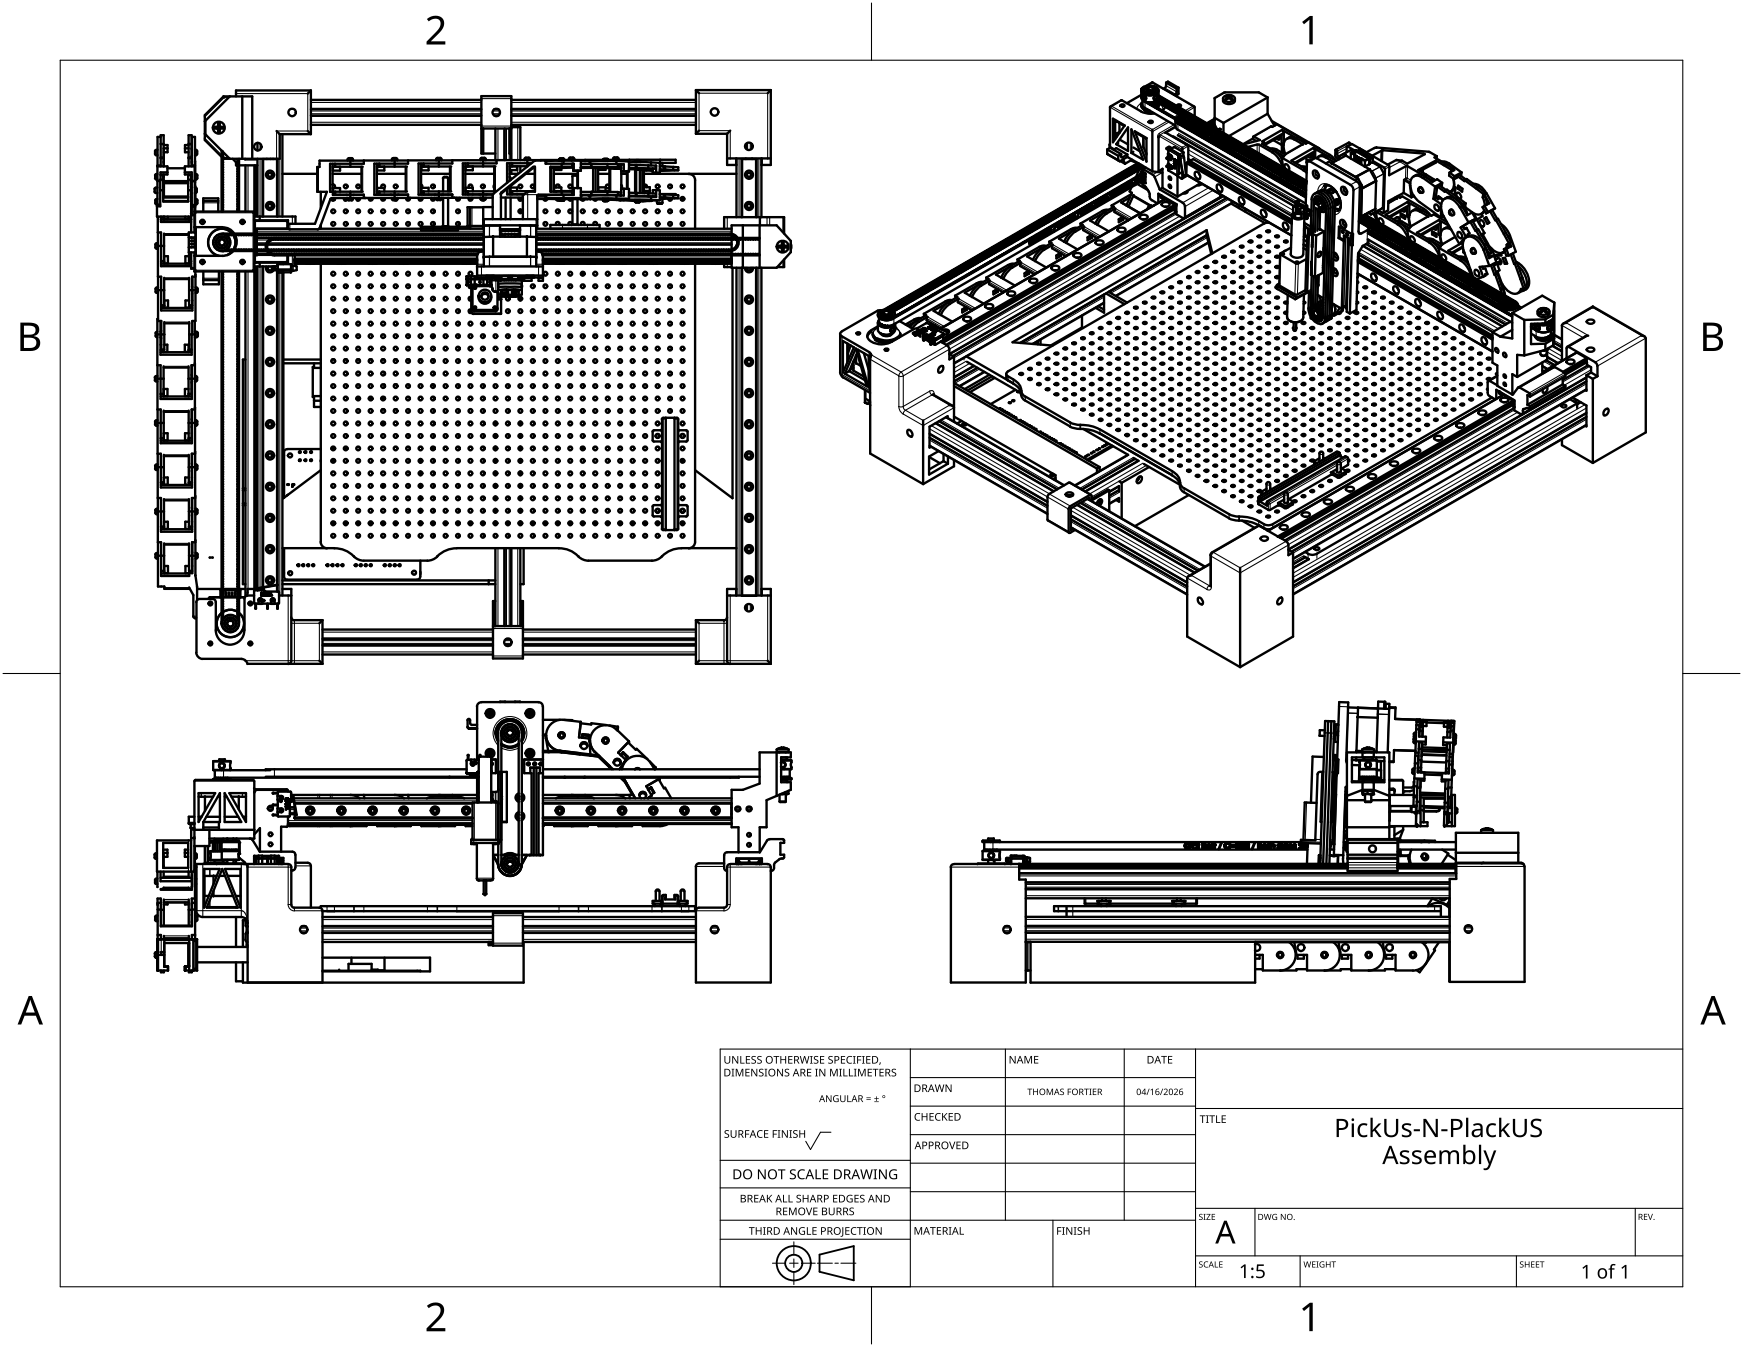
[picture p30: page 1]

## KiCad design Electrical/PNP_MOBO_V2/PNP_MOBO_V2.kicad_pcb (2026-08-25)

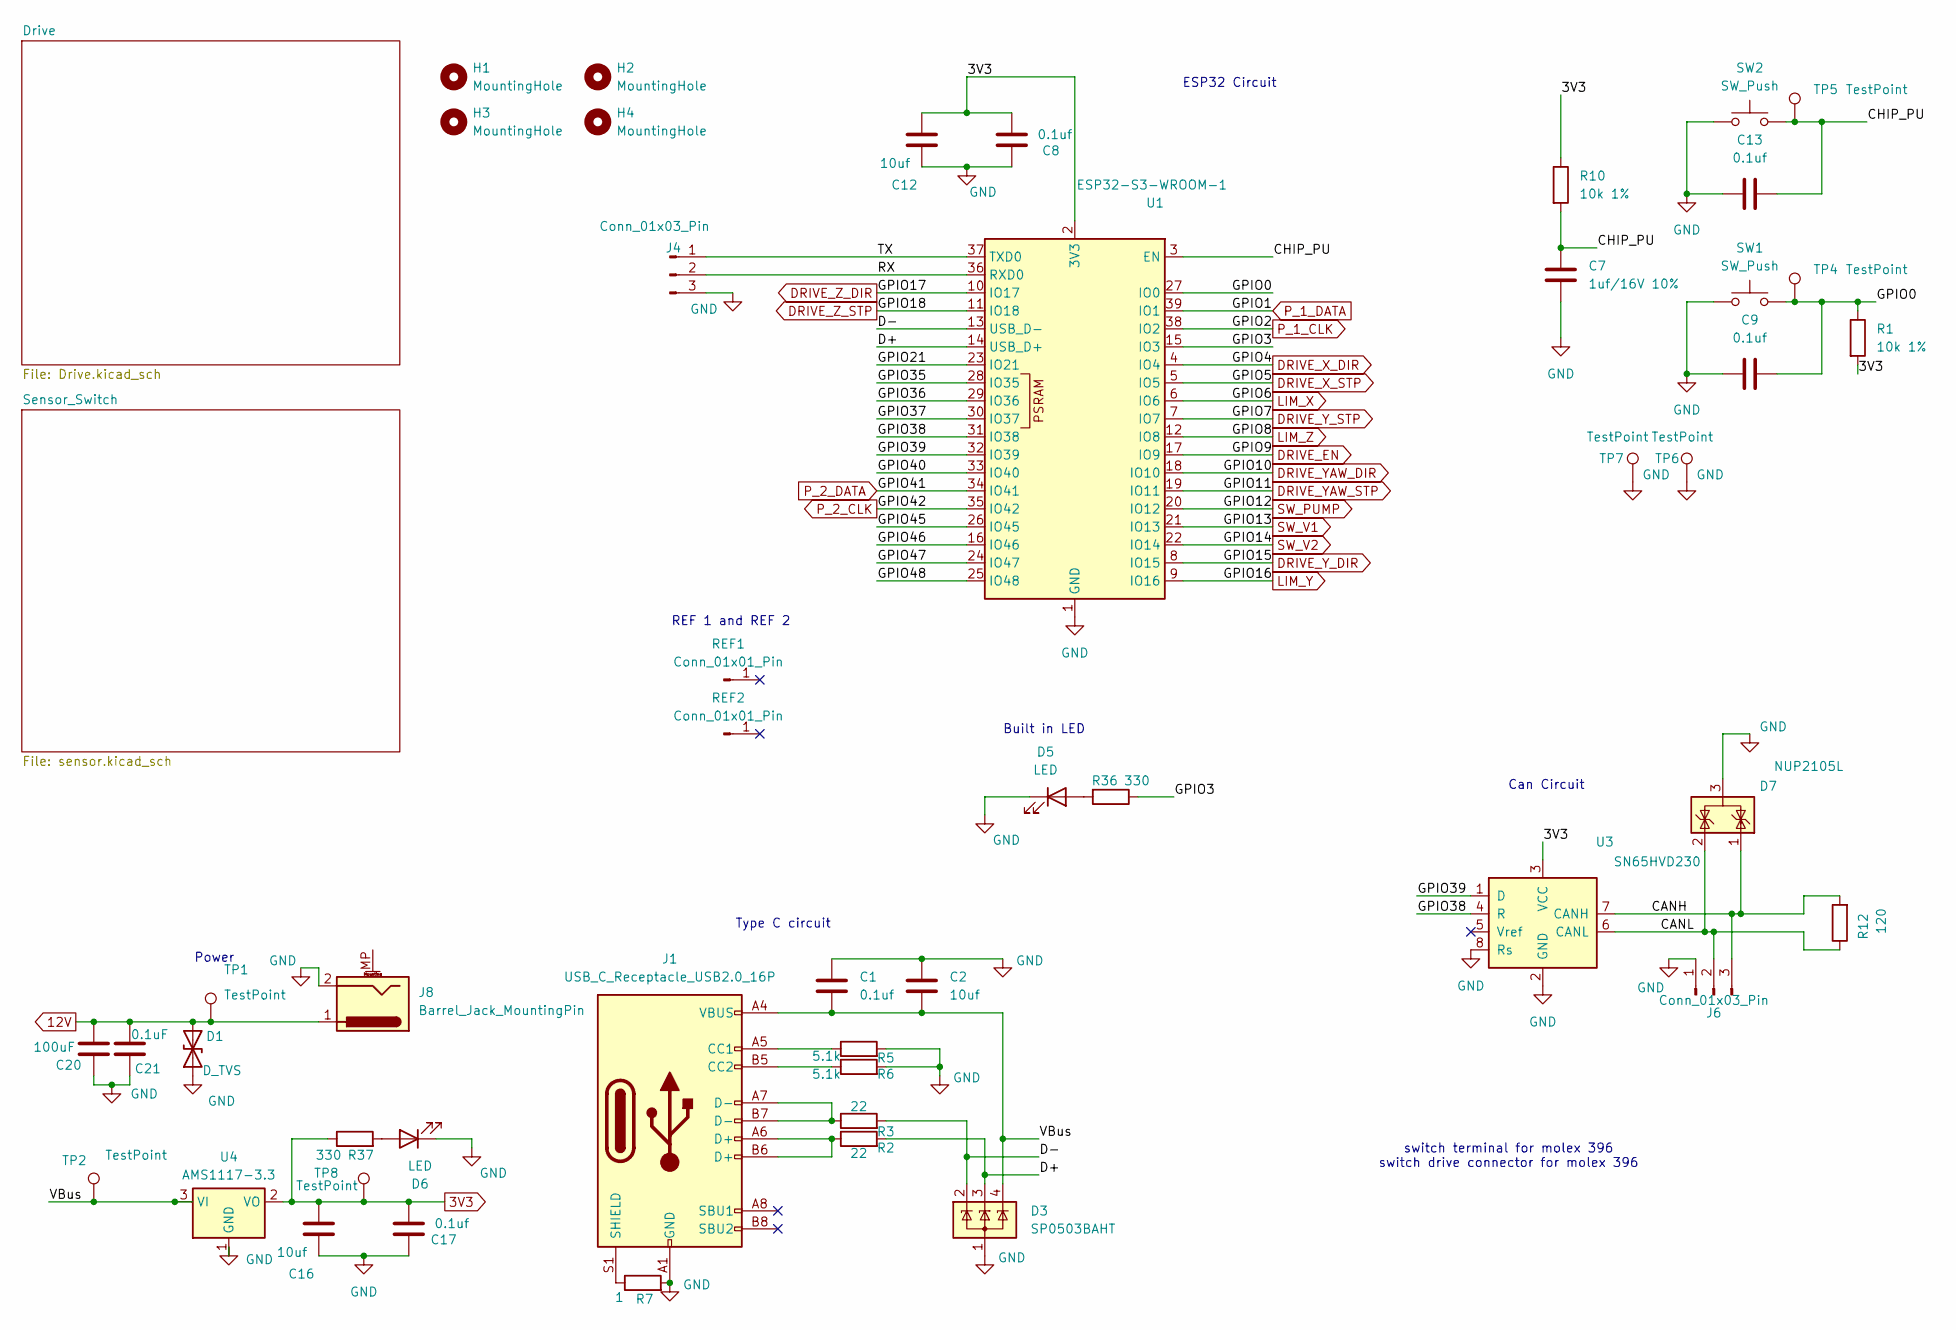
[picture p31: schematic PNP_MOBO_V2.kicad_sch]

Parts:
C1, C8, C9, C13, C17: 0.1uf; C_0603_1608Metric_Pad1.08x0.95mm_HandSolder
C2, C12, C16: 10uf; C_0603_1608Metric_Pad1.08x0.95mm_HandSolder
C7: 1uf/16V 10%; C_0603_1608Metric_Pad1.08x0.95mm_HandSolder
C20: 100uF; CP_Elec_8x10
C21: 0.1uF; C_0603_1608Metric_Pad1.08x0.95mm_HandSolder
D1: D_TVS; D_SMB
D3: SP0503BAHT; SOT-143
D5, D6: LED; LED_0603_1608Metric
D7: NUP2105L; SOT-23
H1, H2, H3, H4: MountingHole; MountingHole_3.2mm_M3
J1: USB_C_Receptacle_USB2.0_16P; USB_C_Receptacle_GCT_USB4105-xx-A_16P_TopMnt_Horizontal
J4: Conn_01x03_Pin; PinHeader_1x03_P2.54mm_Vertical
J6: Conn_01x03_Pin; Molex_KK-254_AE-6410-03A_1x03_P2.54mm_Vertical
J8: Barrel_Jack_MountingPin; BarrelJack_CUI_PJ-063AH_Horizontal
R1, R10: 10k 1%; R_0603_1608Metric_Pad0.98x0.95mm_HandSolder
R2, R3: 22; R_0603_1608Metric_Pad0.98x0.95mm_HandSolder
R5, R6: 5.1k; R_0603_1608Metric_Pad0.98x0.95mm_HandSolder
R7: 1; R_0603_1608Metric_Pad0.98x0.95mm_HandSolder
R12: 120; R_0603_1608Metric_Pad0.98x0.95mm_HandSolder
R36, R37: 330; R_0603_1608Metric_Pad0.98x0.95mm_HandSolder
REF1, REF2: Conn_01x01_Pin; PinHeader_1x01_P1.00mm_Vertical
SW1, SW2: SW_Push; SW_SPST_PTS647_Sx38
TP1, TP2, TP4, TP5, TP6, TP7, TP8: TestPoint; TestPoint_Pad_D2.0mm
U1: ESP32-S3-WROOM-1
U3: SN65HVD230; SOIC-8_3.9x4.9mm_P1.27mm
U4: AMS1117-3.3; SOT-223-3_TabPin2

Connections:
3V3: C8.2, C12.2, C16.2, C17.2, R1.2, R10.1, R37.1, TP8.1, U1.2 (3V3), U3.3 (VCC), U4.2 (VO); also elsewhere on the board
/CANH: D7.1 (K), J6.3, R12.2, U3.7 (CANH)
/CANL: D7.2 (K), J6.2, R12.1, U3.6 (CANL)
/CHIP_PU: C7.1, C13.1, R10.2, SW2.2, TP5.1, U1.3 (EN)
/D+: D3.3 (K), R2.2, U1.14 (USB_D+)
/D-: D3.2 (K), R3.2, U1.13 (USB_D-)
/GPIO0: C9.1, R1.1, SW1.2, TP4.1, U1.27 (IO0)
/GPIO3: R36.1, U1.15 (IO3)
/GPIO21: U1.23 (IO21)
/GPIO35: U1.28 (IO35)
/GPIO36: U1.29 (IO36)
/GPIO37: U1.30 (IO37)
/GPIO38: U1.31 (IO38), U3.4 (R)
/GPIO39: U1.32 (IO39), U3.1 (D)
/GPIO40: U1.33 (IO40)
/GPIO45: U1.26 (IO45)
/GPIO46: U1.16 (IO46)
/GPIO47: U1.24 (IO47)
/GPIO48: U1.25 (IO48)
/RX: J4.2, U1.36 (RXD0)
/TX: J4.1, U1.37 (TXD0)
/VBus: C1.2, C2.2, D3.4 (K), J1.A4 (VBUS), J1.A9 (VBUS), J1.B4 (VBUS), J1.B9 (VBUS), TP2.1, U4.3 (VI)
DRIVE_EN: U1.17 (IO9); also elsewhere on the board
DRIVE_X_DIR: U1.4 (IO4); also elsewhere on the board
DRIVE_X_STP: U1.5 (IO5); also elsewhere on the board
DRIVE_YAW_DIR: U1.18 (IO10); also elsewhere on the board
DRIVE_YAW_STP: U1.19 (IO11); also elsewhere on the board
DRIVE_Y_DIR: U1.8 (IO15); also elsewhere on the board
DRIVE_Y_STP: U1.7 (IO7); also elsewhere on the board
DRIVE_Z_DIR: U1.10 (IO17); also elsewhere on the board
DRIVE_Z_STP: U1.11 (IO18); also elsewhere on the board
LIM_X: U1.6 (IO6); also elsewhere on the board
LIM_Y: U1.9 (IO16); also elsewhere on the board
LIM_Z: U1.12 (IO8); also elsewhere on the board
unnamed: D5.2 (A), R36.2
unnamed: D6.2 (A), R37.2
unnamed: J1.A5 (CC1), R5.1
unnamed: J1.B5 (CC2), R6.1
unnamed: J1.A6 (D+), J1.B6 (D+), R2.1
unnamed: J1.A7 (D-), J1.B7 (D-), R3.1
unnamed: J1.S1 (SHIELD), R7.1
P_1_CLK: U1.38 (IO2); also elsewhere on the board
P_1_DATA: U1.39 (IO1); also elsewhere on the board
P_2_CLK: U1.35 (IO42); also elsewhere on the board
P_2_DATA: U1.34 (IO41); also elsewhere on the board
SW_PUMP: U1.20 (IO12); also elsewhere on the board
SW_V1: U1.21 (IO13); also elsewhere on the board
SW_V2: U1.22 (IO14); also elsewhere on the board

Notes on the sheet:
Built in LED
Type C circuit
Can Circuit
Power
REF 1 and REF 2
ESP32 Circuit
switch terminal for molex 396 switch drive connector for molex 396

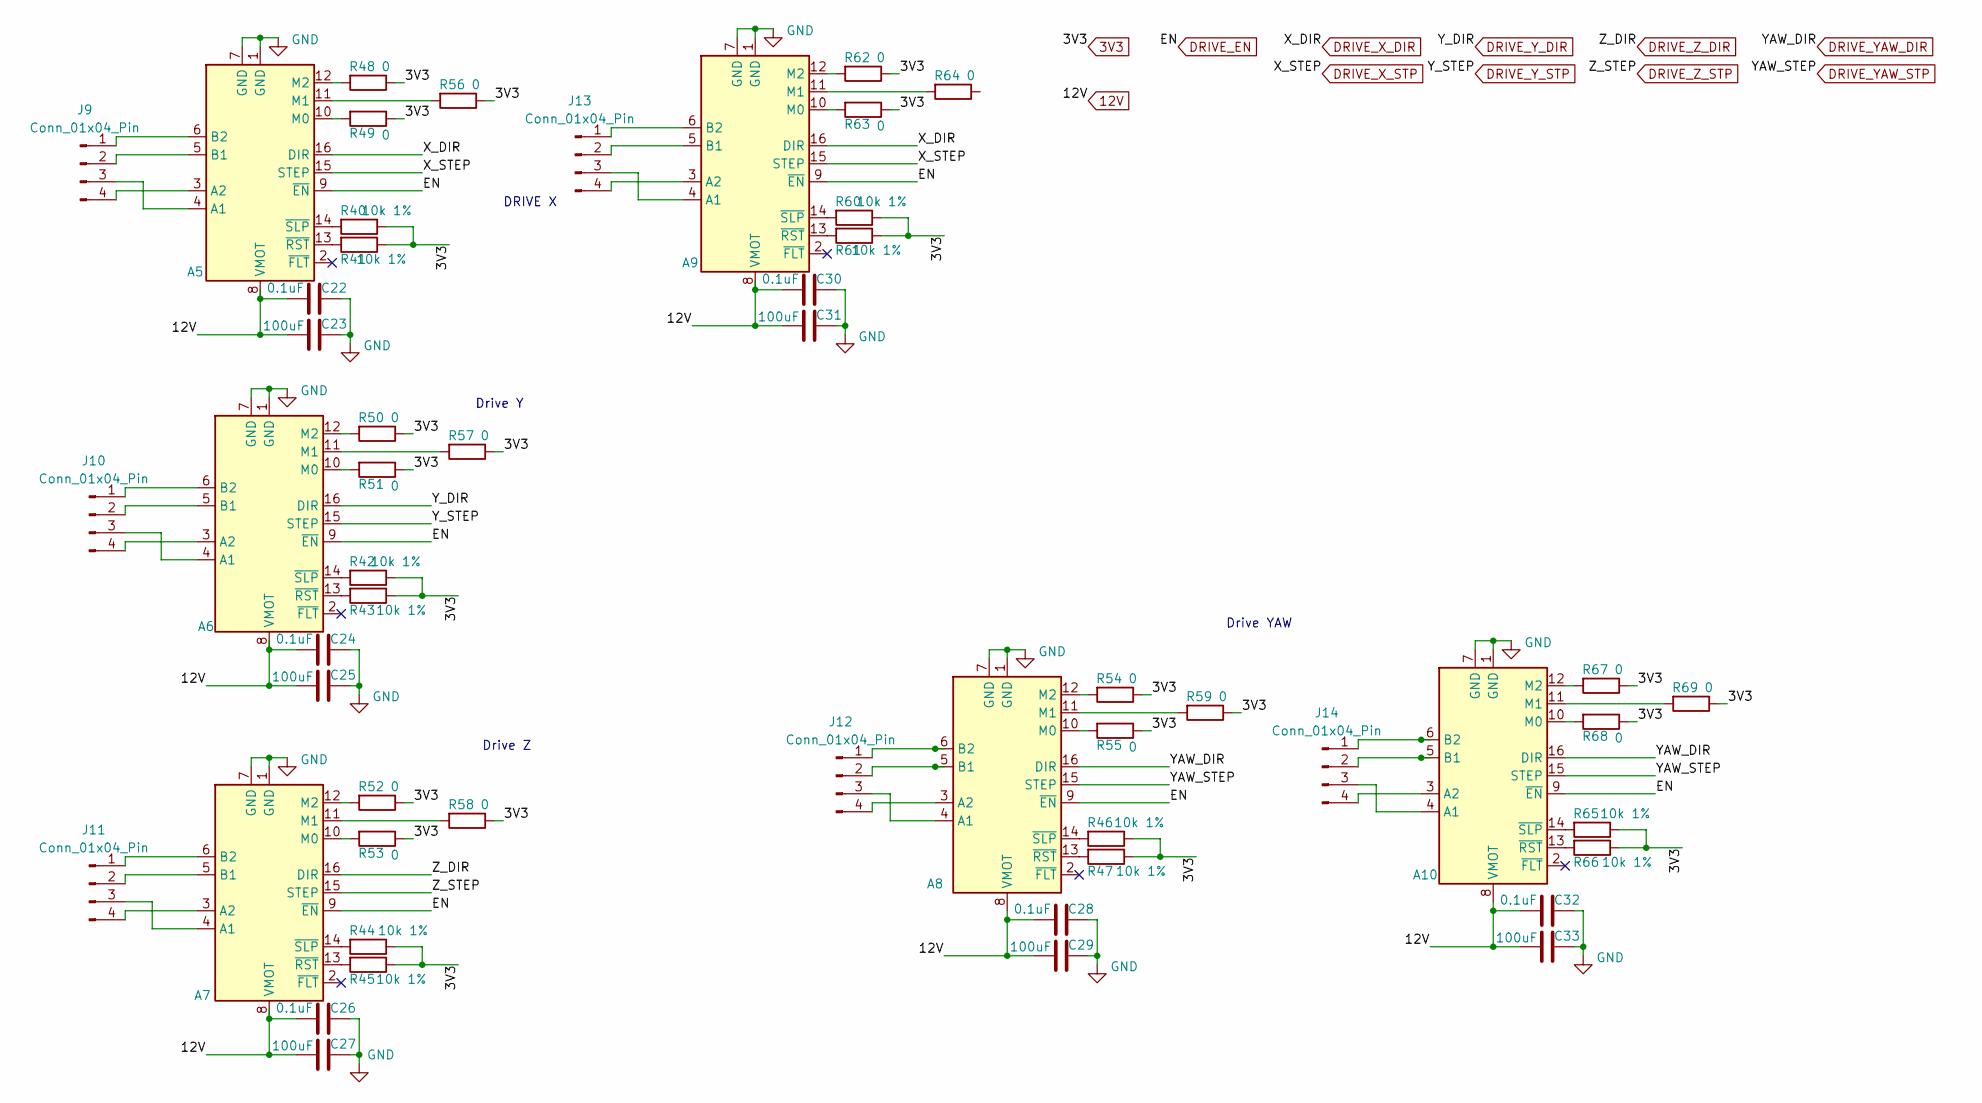
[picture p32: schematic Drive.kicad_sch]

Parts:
A5, A6, A7, A8, A9, A10: Pololu_Breakout_DRV8825; Pololu_Breakout-16_15.2x20.3mm
C22, C24, C26, C28, C30, C32: 0.1uF; C_0603_1608Metric_Pad1.08x0.95mm_HandSolder
C23, C25, C27, C29, C31, C33: 100uF; CP_Elec_8x10
J9, J10, J11, J12, J13, J14: Conn_01x04_Pin; JST_XH_B4B-XH-A_1x04_P2.50mm_Vertical
R40, R41, R42, R43, R44, R45, R46, R47, R60, R61, R65, R66: 10k 1%; R_0603_1608Metric_Pad0.98x0.95mm_HandSolder
R48, R49, R50, R51, R52, R53, R54, R55, R56, R57, R58, R59, R62, R63, R64, R67, R68, R69: 0; R_0402_1005Metric

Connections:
3V3: R40.1, R41.1, R42.1, R43.1, R44.1, R45.1, R46.1, R47.1, R48.1, R49.1, R50.1, R51.1, R52.1, R53.1, R54.1, R55.1, R56.1, R57.1, R58.1, R59.1, R60.1, R61.1, R62.1, R63.1, R65.1, R66.1, R67.1, R68.1, R69.1; also elsewhere on the board
DRIVE_EN: A5.9 (~EN), A6.9 (~EN), A7.9 (~EN), A8.9 (~EN), A9.9 (~EN), A10.9 (~EN); also elsewhere on the board
DRIVE_X_DIR: A5.16 (DIR), A9.16 (DIR); also elsewhere on the board
DRIVE_X_STP: A5.15 (STEP), A9.15 (STEP); also elsewhere on the board
DRIVE_YAW_DIR: A8.16 (DIR), A10.16 (DIR); also elsewhere on the board
DRIVE_YAW_STP: A8.15 (STEP), A10.15 (STEP); also elsewhere on the board
DRIVE_Y_DIR: A6.16 (DIR); also elsewhere on the board
DRIVE_Y_STP: A6.15 (STEP); also elsewhere on the board
DRIVE_Z_DIR: A7.16 (DIR); also elsewhere on the board
DRIVE_Z_STP: A7.15 (STEP); also elsewhere on the board
unnamed: A5.4 (A1), J9.3
unnamed: A5.3 (A2), J9.4
unnamed: A5.5 (B1), J9.2
unnamed: A5.6 (B2), J9.1
unnamed: A5.10 (M0), R49.2
unnamed: A5.11 (M1), R56.2
unnamed: A5.12 (M2), R48.2
unnamed: A5.13 (~RST), R41.2
unnamed: A5.14 (~SLP), R40.2
unnamed: A6.4 (A1), J10.3
unnamed: A6.3 (A2), J10.4
unnamed: A6.5 (B1), J10.2
unnamed: A6.6 (B2), J10.1
unnamed: A6.10 (M0), R51.2
unnamed: A6.11 (M1), R57.2
unnamed: A6.12 (M2), R50.2
unnamed: A6.13 (~RST), R43.2
unnamed: A6.14 (~SLP), R42.2
unnamed: A7.4 (A1), J11.3
unnamed: A7.3 (A2), J11.4
unnamed: A7.5 (B1), J11.2
unnamed: A7.6 (B2), J11.1
unnamed: A7.10 (M0), R53.2
unnamed: A7.11 (M1), R58.2
unnamed: A7.12 (M2), R52.2
unnamed: A7.13 (~RST), R45.2
unnamed: A7.14 (~SLP), R44.2
unnamed: A8.4 (A1), J12.3
unnamed: A8.3 (A2), J12.4
unnamed: A8.5 (B1), J12.2
unnamed: A8.6 (B2), J12.1
unnamed: A8.10 (M0), R55.2
unnamed: A8.11 (M1), R59.2
unnamed: A8.12 (M2), R54.2
unnamed: A8.13 (~RST), R47.2
unnamed: A8.14 (~SLP), R46.2
unnamed: A9.4 (A1), J13.3
unnamed: A9.3 (A2), J13.4
unnamed: A9.5 (B1), J13.2
unnamed: A9.6 (B2), J13.1
unnamed: A9.10 (M0), R63.2
unnamed: A9.11 (M1), R64.2
unnamed: A9.12 (M2), R62.2
unnamed: A9.13 (~RST), R61.2
unnamed: A9.14 (~SLP), R60.2
unnamed: A10.4 (A1), J14.3
unnamed: A10.3 (A2), J14.4
unnamed: A10.5 (B1), J14.2
unnamed: A10.6 (B2), J14.1
unnamed: A10.10 (M0), R68.2
unnamed: A10.11 (M1), R69.2
unnamed: A10.12 (M2), R67.2
unnamed: A10.13 (~RST), R66.2
unnamed: A10.14 (~SLP), R65.2

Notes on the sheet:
Drive Z
DRIVE X
Drive YAW
Drive Y

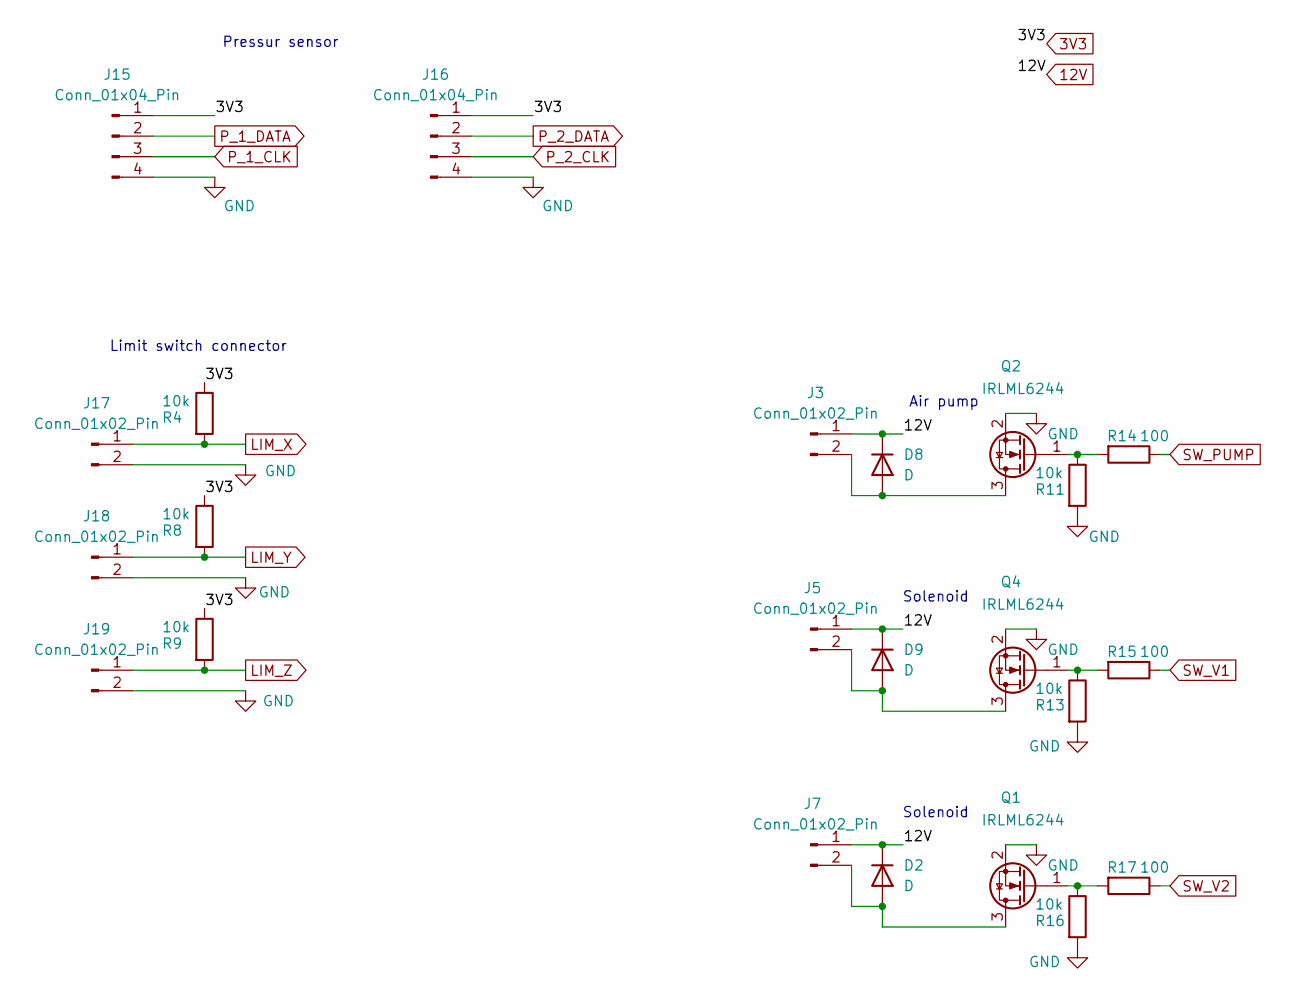
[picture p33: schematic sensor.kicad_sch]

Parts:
D2, D8, D9: D; D_SMB
J3, J5, J7, J17, J18, J19: Conn_01x02_Pin; Molex_KK-254_AE-6410-02A_1x02_P2.54mm_Vertical
J15, J16: Conn_01x04_Pin; PinSocket_1x04_P2.54mm_Vertical
Q1, Q2, Q4: IRLML6244; SOT-23
R4, R8, R9, R11, R13, R16: 10k; R_0603_1608Metric_Pad0.98x0.95mm_HandSolder
R14, R15, R17: 100; R_0603_1608Metric_Pad0.98x0.95mm_HandSolder

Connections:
3V3: J15.1, J16.1, R4.1, R8.1, R9.1; also elsewhere on the board
LIM_X: J17.1, R4.2; also elsewhere on the board
LIM_Y: J18.1, R8.2; also elsewhere on the board
LIM_Z: J19.1, R9.2; also elsewhere on the board
unnamed: D2.2 (A), J7.2, Q1.3 (D)
unnamed: D8.2 (A), J3.2, Q2.3 (D)
unnamed: D9.2 (A), J5.2, Q4.3 (D)
unnamed: Q1.1 (G), R16.1, R17.2
unnamed: Q2.1 (G), R11.1, R14.2
unnamed: Q4.1 (G), R13.1, R15.2
P_1_CLK: J15.3; also elsewhere on the board
P_1_DATA: J15.2; also elsewhere on the board
P_2_CLK: J16.3; also elsewhere on the board
P_2_DATA: J16.2; also elsewhere on the board
SW_PUMP: R14.1; also elsewhere on the board
SW_V1: R15.1; also elsewhere on the board
SW_V2: R17.1; also elsewhere on the board

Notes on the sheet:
Solenoid
Air pump
Limit switch connector
Pressur sensor

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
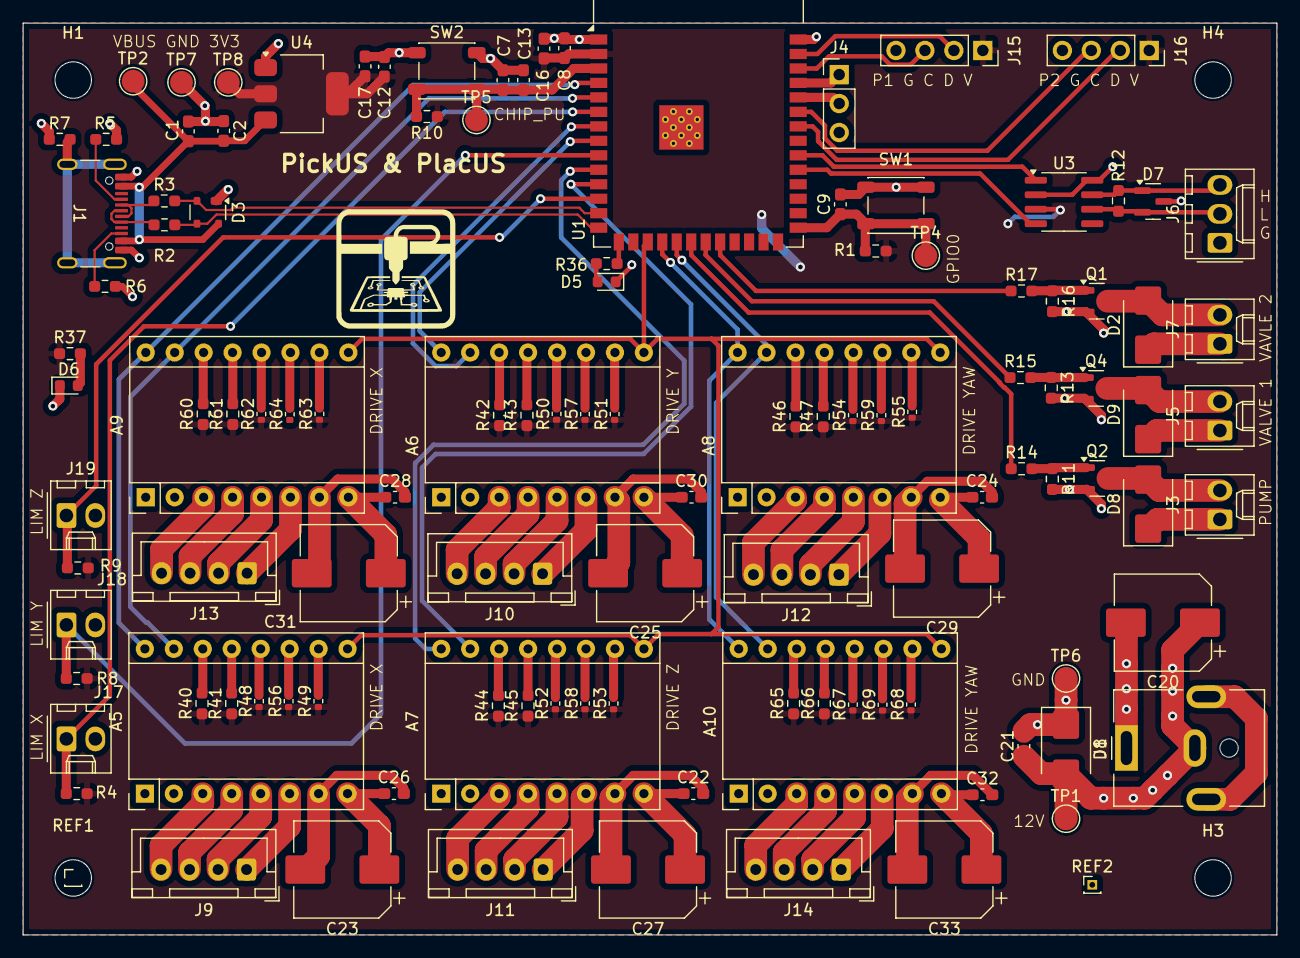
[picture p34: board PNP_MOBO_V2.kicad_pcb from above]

Board: 4 copper layers, 110.0 x 80.0 mm, 125 parts (0 on the bottom side), 101 nets.

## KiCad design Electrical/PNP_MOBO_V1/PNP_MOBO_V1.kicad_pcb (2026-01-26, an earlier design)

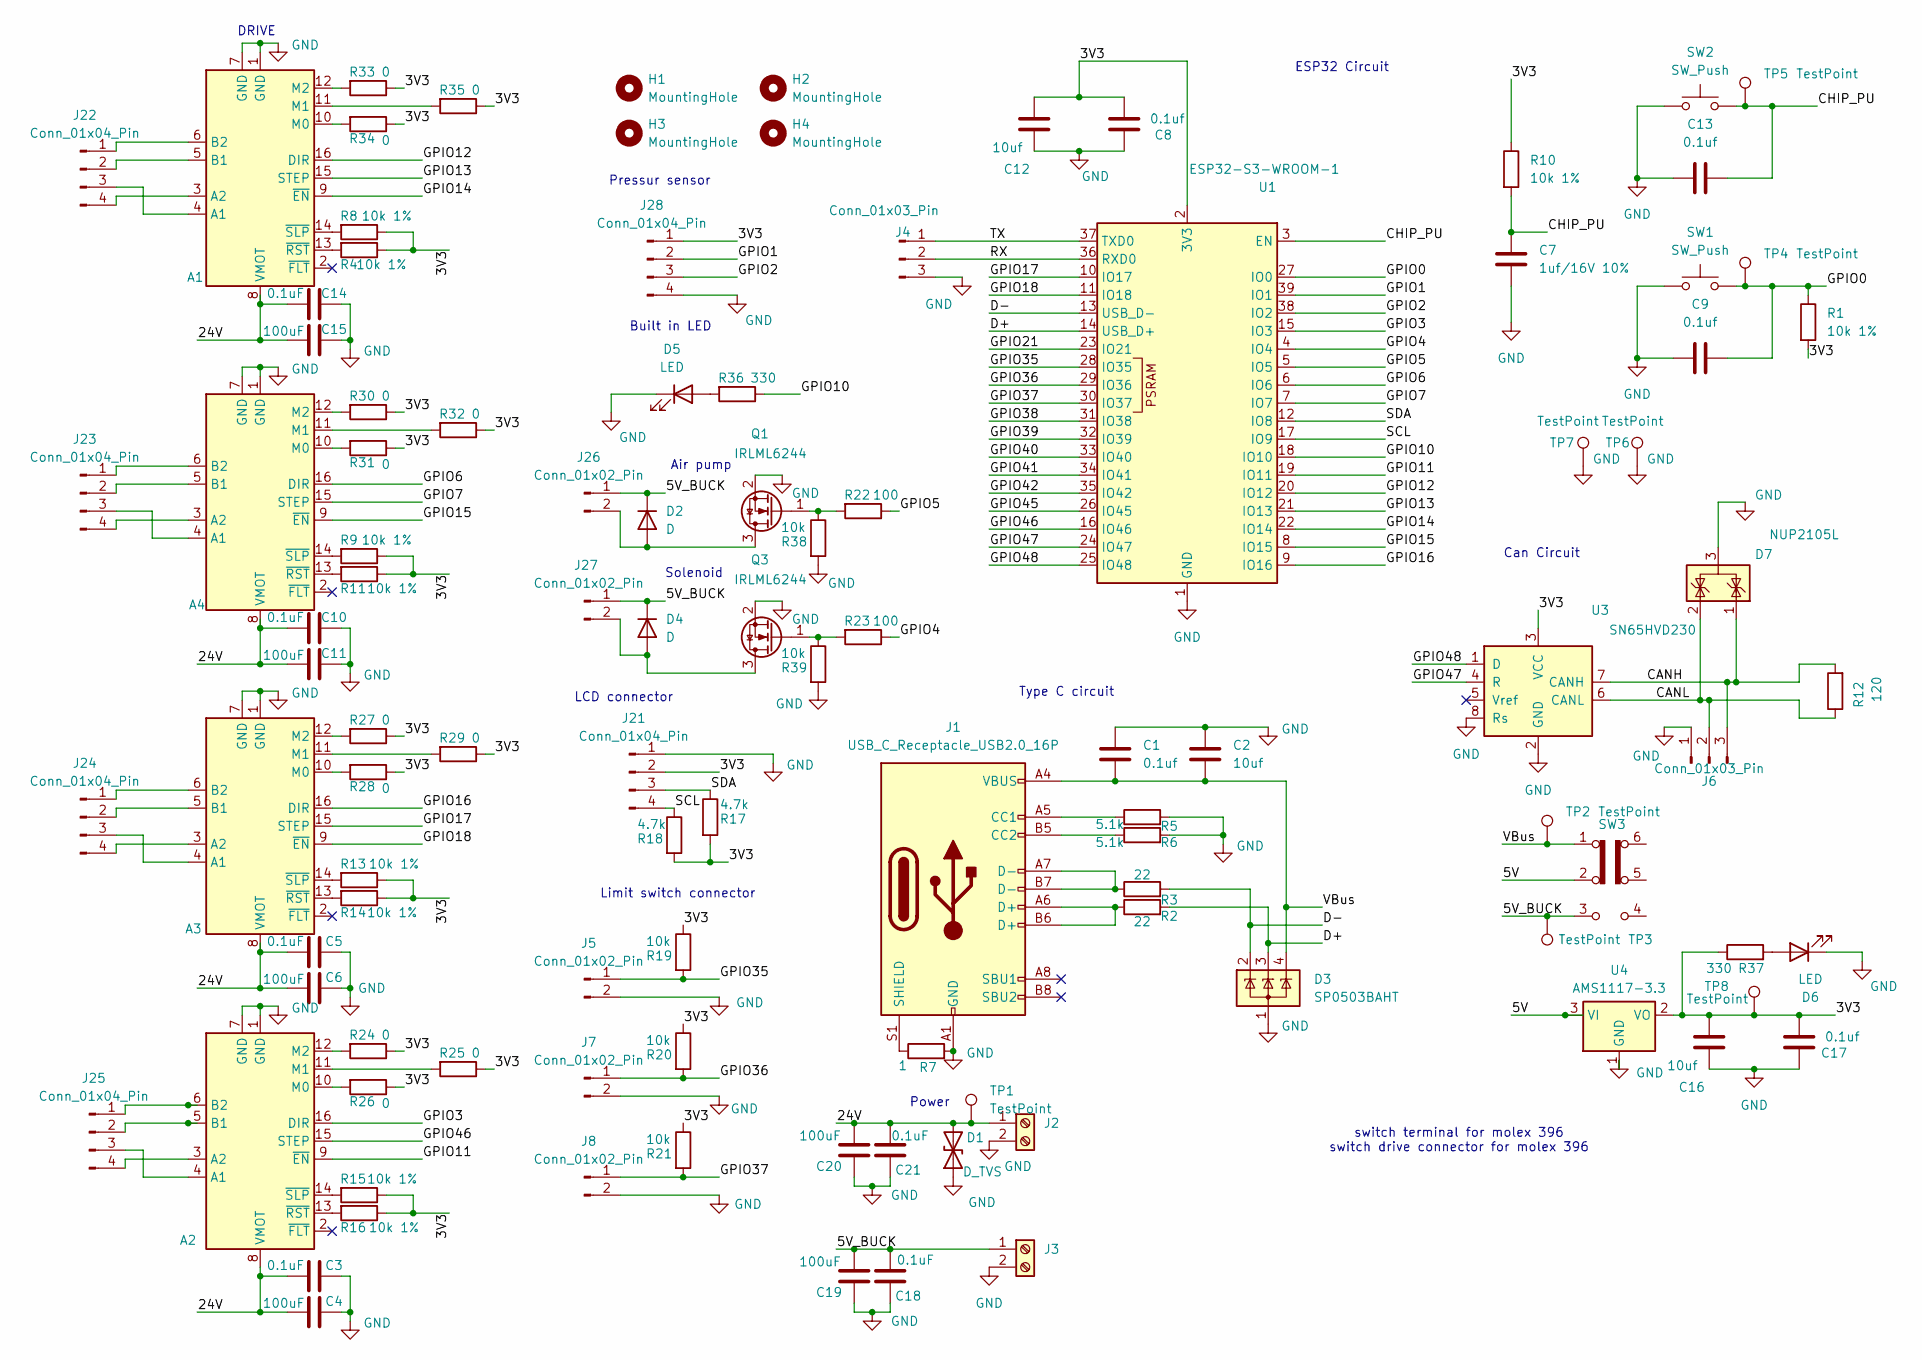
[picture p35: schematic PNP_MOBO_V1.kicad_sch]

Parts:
A1, A2, A3, A4: Pololu_Breakout_DRV8825; Pololu_Breakout-16_15.2x20.3mm
C1, C8, C9, C13, C17: 0.1uf; C_0603_1608Metric_Pad1.08x0.95mm_HandSolder
C2, C12, C16: 10uf; C_0603_1608Metric_Pad1.08x0.95mm_HandSolder
C3, C5, C10, C14, C18, C21: 0.1uF; C_0603_1608Metric_Pad1.08x0.95mm_HandSolder
C4, C6, C11, C15, C19, C20: 100uF; CP_Elec_8x10
C7: 1uf/16V 10%; C_0603_1608Metric_Pad1.08x0.95mm_HandSolder
D1: D_TVS; D_SMB
D2, D4: D; D_SMB
D3: SP0503BAHT; SOT-143
D5, D6: LED; LED_0603_1608Metric
D7: NUP2105L; SOT-23
H1, H2, H3, H4: MountingHole; MountingHole_3.2mm_M3
J1: USB_C_Receptacle_USB2.0_16P; USB_C_Receptacle_GCT_USB4105-xx-A_16P_TopMnt_Horizontal
J2, J3: Screw_Terminal_01x02; Molex_KK-396_A-41792-0002_1x02_P3.96mm_Horizontal
J4: Conn_01x03_Pin; PinHeader_1x03_P2.54mm_Vertical
J5, J7, J8, J26, J27: Conn_01x02_Pin; Molex_KK-254_AE-6410-02A_1x02_P2.54mm_Vertical
J6: Conn_01x03_Pin; Molex_KK-254_AE-6410-03A_1x03_P2.54mm_Vertical
J21: Conn_01x04_Pin; Molex_KK-254_AE-6410-04A_1x04_P2.54mm_Vertical
J22, J23, J24, J25: Conn_01x04_Pin; Molex_KK-396_A-41792-0004_1x04_P3.96mm_Horizontal
J28: Conn_01x04_Pin; PinSocket_1x04_P2.54mm_Vertical
Q1, Q3: IRLML6244; SOT-23
R1, R4, R8, R9, R10, R11, R13, R14, R15, R16: 10k 1%; R_0603_1608Metric_Pad0.98x0.95mm_HandSolder
R2, R3: 22; R_0603_1608Metric_Pad0.98x0.95mm_HandSolder
R5, R6: 5.1k; R_0603_1608Metric_Pad0.98x0.95mm_HandSolder
R7: 1; R_0603_1608Metric_Pad0.98x0.95mm_HandSolder
R12: 120; R_0603_1608Metric_Pad0.98x0.95mm_HandSolder
R17, R18: 4.7k; R_0603_1608Metric_Pad0.98x0.95mm_HandSolder
R19, R20, R21, R38, R39: 10k; R_0603_1608Metric_Pad0.98x0.95mm_HandSolder
R22, R23: 100; R_0603_1608Metric_Pad0.98x0.95mm_HandSolder
R24, R25, R26, R27, R28, R29, R30, R31, R32, R33, R34, R35: 0; R_0603_1608Metric_Pad0.98x0.95mm_HandSolder
R36, R37: 330; R_0603_1608Metric_Pad0.98x0.95mm_HandSolder
SW1, SW2: SW_Push; SW_SPST_PTS647_Sx38
SW3: SW_Slide_DPDT; SW_SLW-1678105-6A-N-D
TP1, TP2, TP3, TP4, TP5, TP6, TP7, TP8: TestPoint; TestPoint_Pad_D2.0mm
U1: ESP32-S3-WROOM-1
U3: SN65HVD230; SOIC-8_3.9x4.9mm_P1.27mm
U4: AMS1117-3.3; SOT-223-3_TabPin2

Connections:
/3V3: C8.2, C12.2, C16.2, C17.2, J21.2, J28.1, R1.2, R4.1, R8.1, R9.1, R10.1, R11.1, R13.1, R14.1, R15.1, R16.1, R17.2, R18.2, R19.1, R20.1, R21.1, R24.1, R25.1, R26.1, R27.1, R28.1, R29.1, R30.1, R31.1, R32.1, R33.1, R34.1, R35.1, R37.1, TP8.1, U1.2 (3V3), U3.3 (VCC), U4.2 (VO)
/5V: SW3.2 (B), U4.3 (VI); also elsewhere on the board
/5V_BUCK: C18.1, C19.1, D2.1 (K), D4.1 (K), J3.1, J26.1, J27.1, SW3.3 (C), TP3.1
/24V: A1.8 (VMOT), A2.8 (VMOT), A3.8 (VMOT), A4.8 (VMOT), C3.1, C4.1, C5.1, C6.1, C10.1, C11.1, C14.1, C15.1, C20.1, C21.1, D1.2 (A2), J2.1, TP1.1
/CANH: D7.1 (K), J6.3, R12.2, U3.7 (CANH)
/CANL: D7.2 (K), J6.2, R12.1, U3.6 (CANL)
/CHIP_PU: C7.1, C13.1, R10.2, SW2.2, TP5.1, U1.3 (EN)
/D+: D3.3 (K), R2.2, U1.14 (USB_D+)
/D-: D3.2 (K), R3.2, U1.13 (USB_D-)
/GPIO0: C9.1, R1.1, SW1.2, TP4.1, U1.27 (IO0)
/GPIO1: J28.2, U1.39 (IO1)
/GPIO2: J28.3, U1.38 (IO2)
/GPIO3: A2.16 (DIR), U1.15 (IO3)
/GPIO4: R23.1, U1.4 (IO4)
/GPIO5: R22.1, U1.5 (IO5)
/GPIO6: A4.16 (DIR), U1.6 (IO6)
/GPIO7: A4.15 (STEP), U1.7 (IO7)
/GPIO10: R36.1, U1.18 (IO10)
/GPIO11: A2.9 (~EN), U1.19 (IO11)
/GPIO12: A1.16 (DIR), U1.20 (IO12)
/GPIO13: A1.15 (STEP), U1.21 (IO13)
/GPIO14: A1.9 (~EN), U1.22 (IO14)
/GPIO15: A4.9 (~EN), U1.8 (IO15)
/GPIO16: A3.16 (DIR), U1.9 (IO16)
/GPIO17: A3.15 (STEP), U1.10 (IO17)
/GPIO18: A3.9 (~EN), U1.11 (IO18)
/GPIO21: U1.23 (IO21)
/GPIO35: J5.1, R19.2, U1.28 (IO35)
/GPIO36: J7.1, R20.2, U1.29 (IO36)
/GPIO37: J8.1, R21.2, U1.30 (IO37)
/GPIO38: U1.31 (IO38)
/GPIO39: U1.32 (IO39)
/GPIO40: U1.33 (IO40)
/GPIO41: U1.34 (IO41)
/GPIO42: U1.35 (IO42)
/GPIO45: U1.26 (IO45)
/GPIO46: A2.15 (STEP), U1.16 (IO46)
/GPIO47: U1.24 (IO47), U3.4 (R)
/GPIO48: U1.25 (IO48), U3.1 (D)
/RX: J4.2, U1.36 (RXD0)
/SCL: J21.4, R18.1, U1.17 (IO9)
/SDA: J21.3, R17.1, U1.12 (IO8)
/TX: J4.1, U1.37 (TXD0)
/VBus: C1.2, C2.2, D3.4 (K), J1.A4 (VBUS), J1.A9 (VBUS), J1.B4 (VBUS), J1.B9 (VBUS), SW3.1 (A), TP2.1
GND: A1.1 (GND), A1.7 (GND), A2.1 (GND), A2.7 (GND), A3.1 (GND), A3.7 (GND), A4.1 (GND), A4.7 (GND), C1.1, C2.1, C3.2, C4.2, C5.2, C6.2, C7.2, C8.1, C9.2, C10.2, C11.2, C12.1, C13.2, C14.2, C15.2, C16.1, C17.1, C18.2, C19.2, C20.2, C21.2, D1.1 (A1), D3.1 (A), D5.1 (K), D6.1 (K), D7.3 (A), J1.A1 (GND), J1.A12 (GND), J1.B1 (GND), J1.B12 (GND), J2.2, J3.2, J4.3, J5.2, J6.1, J7.2, J8.2, J21.1, J28.4, Q1.2 (S), Q3.2 (S), R5.2, R6.2, R7.2, R38.2, R39.2, SW1.1, SW2.1, TP6.1, TP7.1, U1.1 (GND), U1.40 (GND), U1.41 (GND), U3.2 (GND), U3.8 (Rs), U4.1 (GND); also elsewhere on the board
unnamed: A1.4 (A1), J22.3
unnamed: A1.3 (A2), J22.4
unnamed: A1.5 (B1), J22.2
unnamed: A1.6 (B2), J22.1
unnamed: A1.10 (M0), R34.2
unnamed: A1.11 (M1), R35.2
unnamed: A1.12 (M2), R33.2
unnamed: A1.13 (~RST), R4.2
unnamed: A1.14 (~SLP), R8.2
unnamed: A2.4 (A1), J25.3
unnamed: A2.3 (A2), J25.4
unnamed: A2.5 (B1), J25.2
unnamed: A2.6 (B2), J25.1
unnamed: A2.10 (M0), R26.2
unnamed: A2.11 (M1), R25.2
unnamed: A2.12 (M2), R24.2
unnamed: A2.13 (~RST), R16.2
unnamed: A2.14 (~SLP), R15.2
unnamed: A3.4 (A1), J24.3
unnamed: A3.3 (A2), J24.4
unnamed: A3.5 (B1), J24.2
unnamed: A3.6 (B2), J24.1
unnamed: A3.10 (M0), R28.2
unnamed: A3.11 (M1), R29.2
unnamed: A3.12 (M2), R27.2
unnamed: A3.13 (~RST), R14.2
unnamed: A3.14 (~SLP), R13.2
unnamed: A4.4 (A1), J23.3
unnamed: A4.3 (A2), J23.4
unnamed: A4.5 (B1), J23.2
unnamed: A4.6 (B2), J23.1
unnamed: A4.10 (M0), R31.2
unnamed: A4.11 (M1), R32.2
unnamed: A4.12 (M2), R30.2
unnamed: A4.13 (~RST), R11.2
unnamed: A4.14 (~SLP), R9.2
unnamed: D2.2 (A), J26.2, Q1.3 (D)
unnamed: D4.2 (A), J27.2, Q3.3 (D)
unnamed: D5.2 (A), R36.2
unnamed: D6.2 (A), R37.2
unnamed: J1.A5 (CC1), R5.1
unnamed: J1.B5 (CC2), R6.1
unnamed: J1.A6 (D+), J1.B6 (D+), R2.1
unnamed: J1.A7 (D-), J1.B7 (D-), R3.1
unnamed: J1.S1 (SHIELD), R7.1
unnamed: Q1.1 (G), R22.2, R38.1
unnamed: Q3.1 (G), R23.2, R39.1

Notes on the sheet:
Air pump
Limit switch connector
Solenoid
Built in LED
Pressur sensor
LCD connector
Type C circuit
Can Circuit
Power
ESP32 Circuit
DRIVE
switch terminal for molex 396 switch drive connector for molex 396

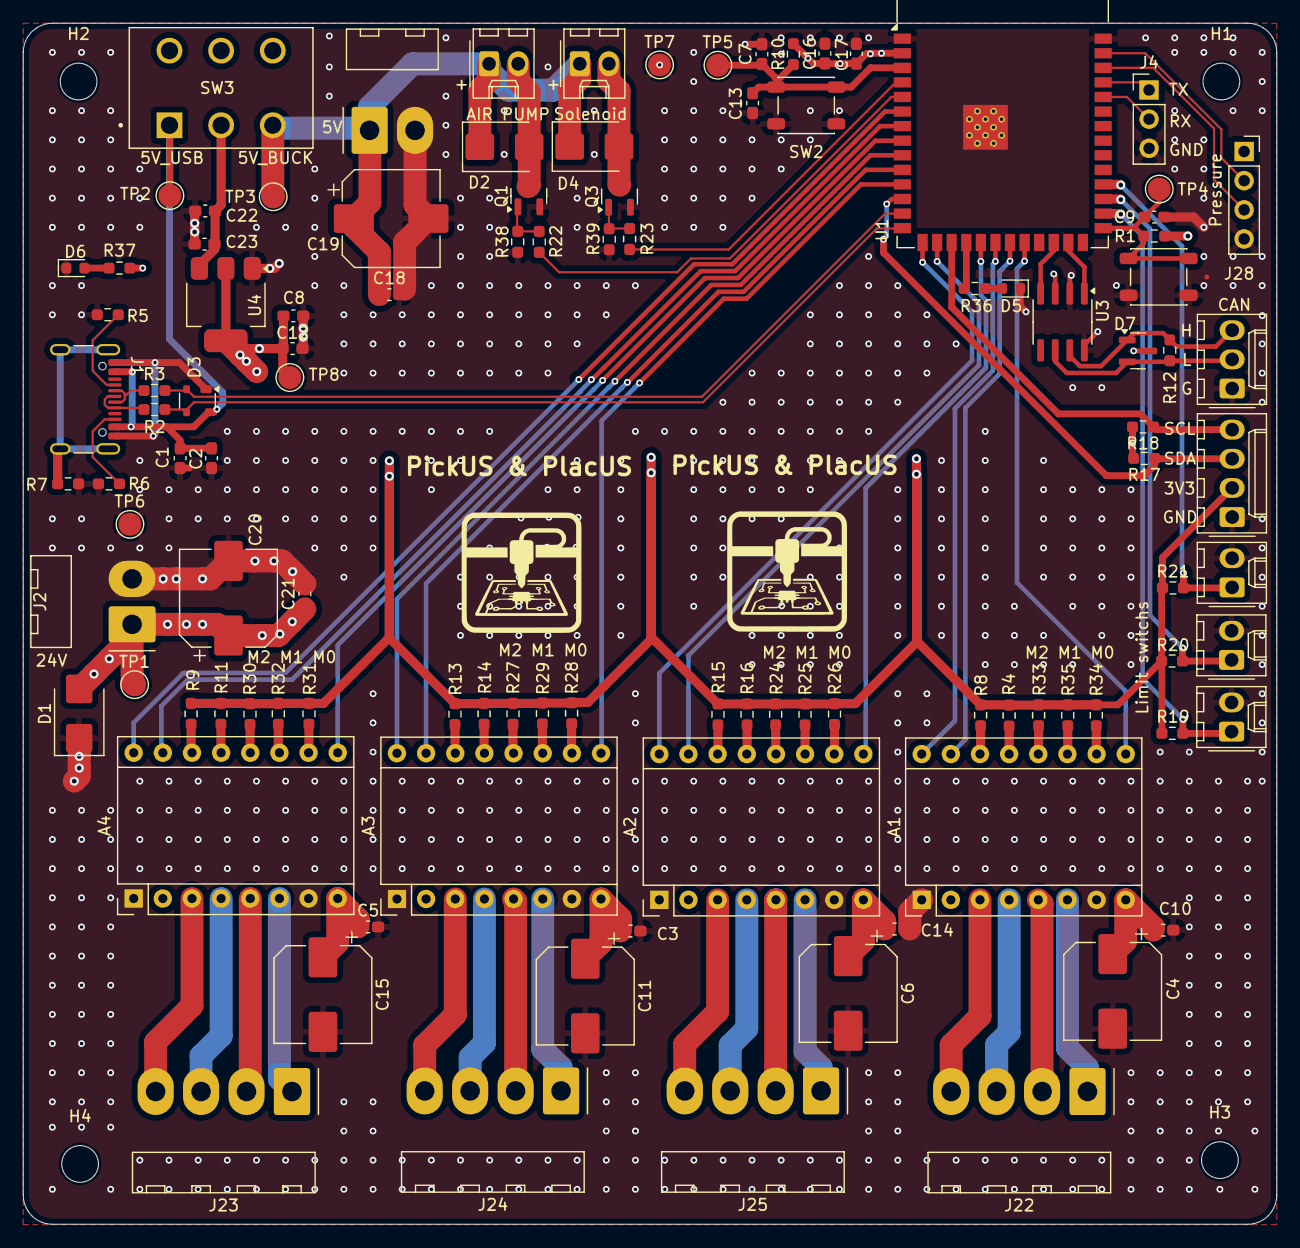
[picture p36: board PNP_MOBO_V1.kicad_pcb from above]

Board: 4 copper layers, 109.2 x 104.6 mm, 109 parts (0 on the bottom side), 85 nets.

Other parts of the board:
C22: 10uf; C_0603_1608Metric_Pad1.08x0.95mm_HandSolder
C23: 0.1uf; C_0603_1608Metric_Pad1.08x0.95mm_HandSolder

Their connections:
/5V: C22.2, C23.2; also elsewhere on the board
GND: C22.1, C23.1; also elsewhere on the board

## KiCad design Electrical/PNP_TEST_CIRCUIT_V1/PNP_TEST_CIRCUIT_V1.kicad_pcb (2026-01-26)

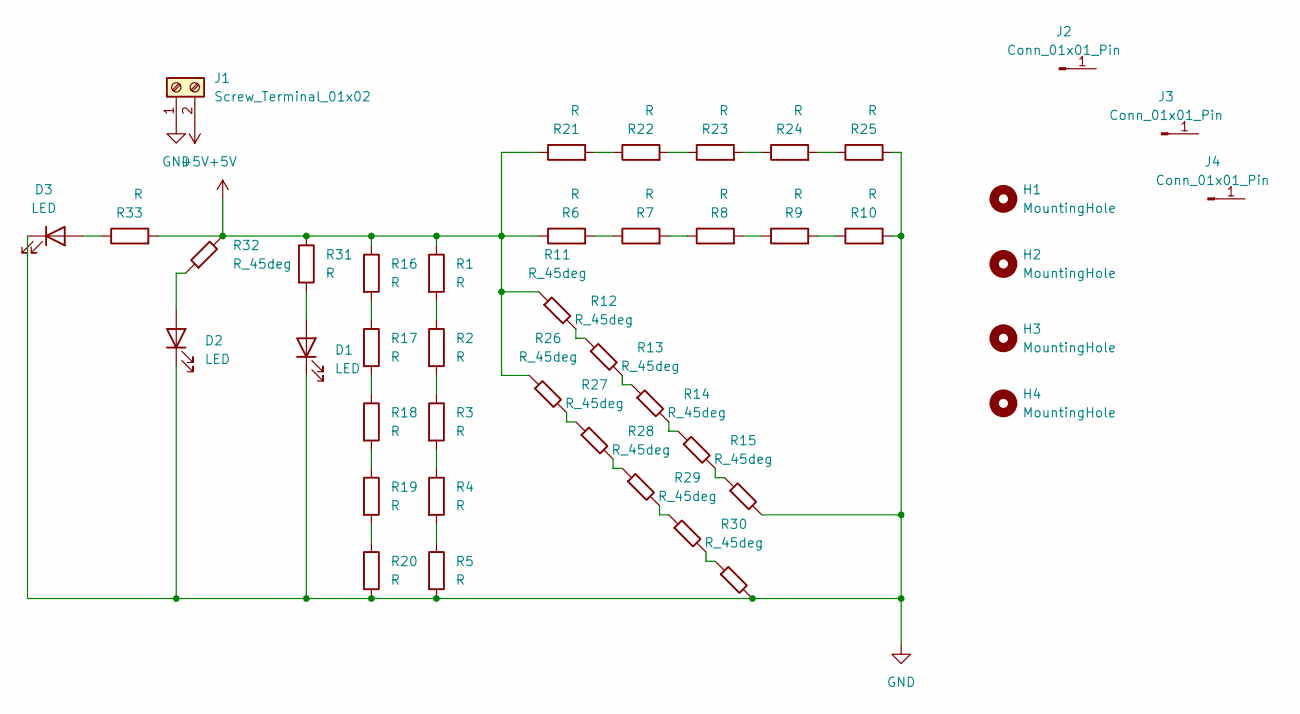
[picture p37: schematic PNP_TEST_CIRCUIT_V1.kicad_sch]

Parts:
D1, D2, D3: LED; LED_0805_2012Metric
H1, H2, H3, H4: MountingHole; MountingHole_3.2mm_M3
J1: Screw_Terminal_01x02; Molex_KK-396_A-41792-0002_1x02_P3.96mm_Horizontal
J2, J3, J4: Conn_01x01_Pin; PinHeader_1x01_P1.00mm_Vertical
R1, R2, R3, R4, R5, R6, R7, R8, R9, R10, R31, R33: R; R_0805_2012Metric
R11, R12, R13, R14, R15, R32: R_45deg; R_0805_2012Metric
R16, R17, R18, R19, R20, R21, R22, R23, R24, R25: R; R_0603_1608Metric
R26, R27, R28, R29, R30: R_45deg; R_0603_1608Metric

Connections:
+5V: J1.2, R1.1, R6.1, R11.1, R16.1, R21.1, R26.1, R31.1, R32.2, R33.2
GND: D1.1 (K), D2.1 (K), D3.1 (K), J1.1, R5.2, R10.2, R15.2, R20.2, R25.2, R30.2
unnamed: D1.2 (A), R31.2
unnamed: D2.2 (A), R32.1
unnamed: D3.2 (A), R33.1
unnamed: R1.2, R2.1
unnamed: R2.2, R3.1
unnamed: R3.2, R4.1
unnamed: R4.2, R5.1
unnamed: R6.2, R7.1
unnamed: R7.2, R8.1
unnamed: R8.2, R9.1
unnamed: R9.2, R10.1
unnamed: R11.2, R12.1
unnamed: R12.2, R13.1
unnamed: R13.2, R14.1
unnamed: R14.2, R15.1
unnamed: R16.2, R17.1
unnamed: R17.2, R18.1
unnamed: R18.2, R19.1
unnamed: R19.2, R20.1
unnamed: R21.2, R22.1
unnamed: R22.2, R23.1
unnamed: R23.2, R24.1
unnamed: R24.2, R25.1
unnamed: R26.2, R27.1
unnamed: R27.2, R28.1
unnamed: R28.2, R29.1
unnamed: R29.2, R30.1

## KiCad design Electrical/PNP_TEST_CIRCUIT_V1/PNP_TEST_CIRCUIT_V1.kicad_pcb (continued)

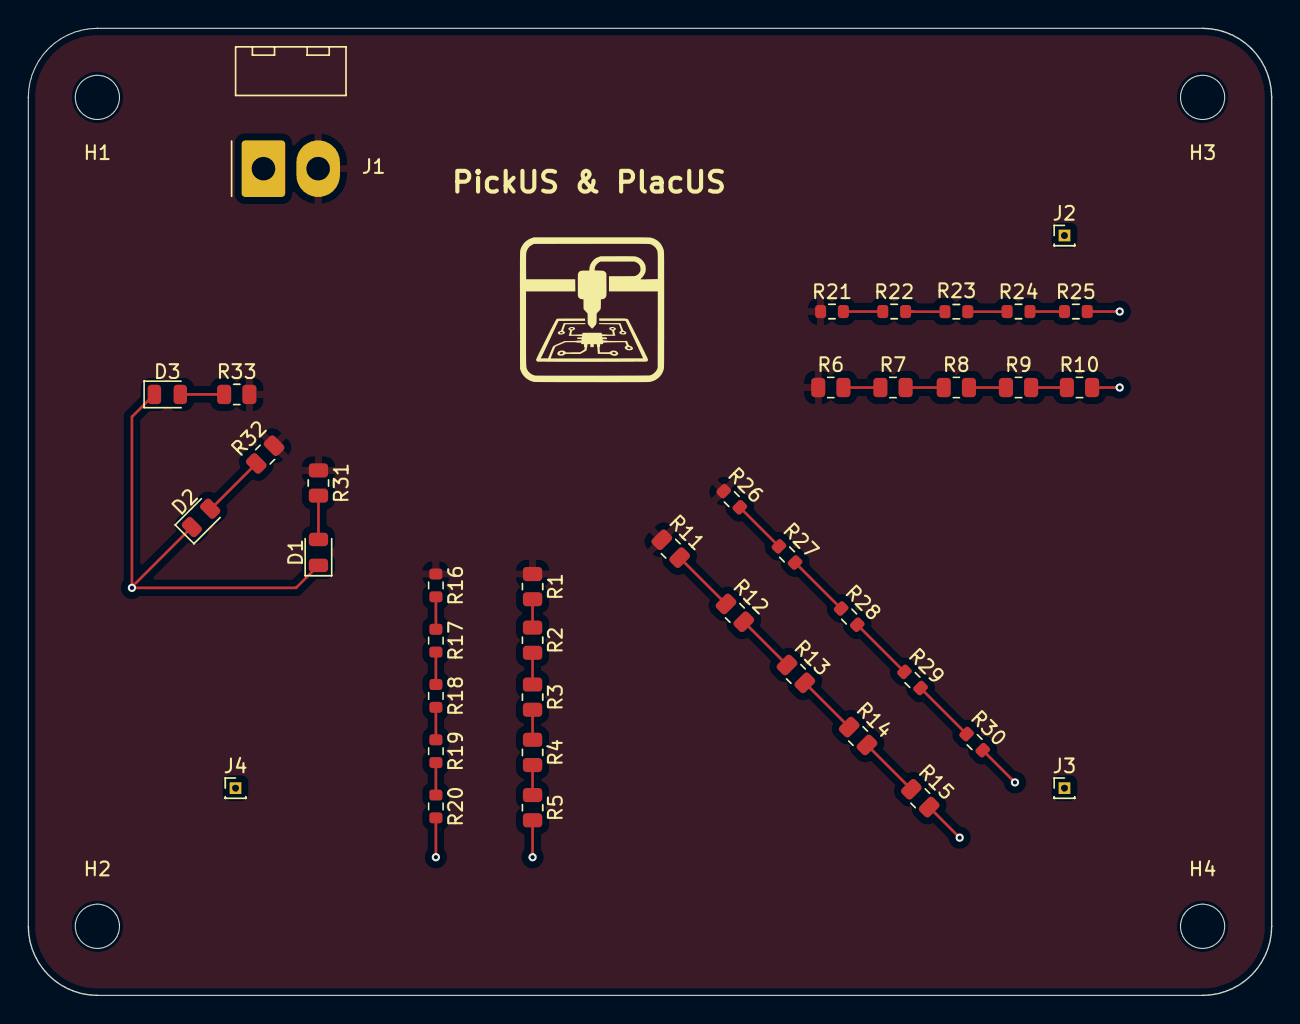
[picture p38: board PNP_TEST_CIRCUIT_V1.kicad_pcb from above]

Board: 2 copper layers, 90.0 x 70.0 mm, 44 parts (0 on the bottom side), 29 nets.

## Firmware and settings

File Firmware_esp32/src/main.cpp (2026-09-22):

#include <Arduino.h>
#include <AccelStepper.h>
#include <MultiStepper.h>

#include "../lib/data.hpp"
#include "BoardConfig.h"
#include "CommandHandler.h"
#include "CommunicationHandler.h"
#include "Controller.h"
#include "DataHandler.h"
#include "commands/HomeCommand.h"
#include "commands/MoveCommand.h"
#include "commands/PickCommand.h"
#include "commands/PlaceCommand.h"
#include "commands/PauseCommand.h"
#include "commands/StopCommand.h"
#include "commands/ValveCommand.h"
#include "commands/PumpCommand.h"
#include "hardware/LimitSwitch.h"
#include "hardware/Mosfet.h"
#include "hardware/PressureSensor.h"

namespace
{
constexpr uint32_t SERIAL_BAUD_RATE = 115200;
constexpr uint32_t SERIAL_STARTUP_DELAY_MS = 500;
constexpr uint32_t COMMUNICATION_TASK_STACK = 10000;
constexpr uint32_t CONTROL_TASK_STACK = 10000;
constexpr uint32_t PRESSURE_TASK_STACK = 4096;
constexpr TickType_t COMMUNICATION_IDLE_DELAY = pdMS_TO_TICKS(1);
constexpr TickType_t COMMUNICATION_DELAY = pdMS_TO_TICKS(10);
constexpr TickType_t PRESSURE_LOOP_DELAY = pdMS_TO_TICKS(50);

static AccelStepper motorX(AccelStepper::DRIVER, PIN_DX_STEP, PIN_DX_DIR);
static AccelStepper motorY(AccelStepper::DRIVER, PIN_DY_STEP, PIN_DY_DIR);
static AccelStepper motorZ(AccelStepper::DRIVER, PIN_DZ_STEP, PIN_DZ_DIR);
static AccelStepper motorYaw(AccelStepper::DRIVER, PIN_DYAW_STEP, PIN_DYAW_DIR);
static MultiStepper motorSystem;

static LimitSwitch limitSwitchX(PIN_LIMSWITCH_X);
static LimitSwitch limitSwitchY(PIN_LIMSWITCH_Y);
static LimitSwitch limitSwitchZ(PIN_LIMSWITCH_Z);

static Mosfet pump(PIN_PUMP);
static Mosfet valve0(PIN_VALVE);
static PressureSensor pressureSensor0(PIN_PSENSOR_CLK, PIN_PSENSOR_DATA);

static CommandHandler commandHandler;

static DataHandlerHardware dataHandlerHw = {
	&motorX,
	&motorY,
	&motorZ,
	&motorYaw,
	{&valve0},
	&pump,
	{&pressureSensor0}
};

static HomingHardware homingHardware = {
	&motorX,
	&motorY,
	&motorZ,
	&motorYaw,
	&limitSwitchX,
	&limitSwitchY,
	&limitSwitchZ
};

static MovingHardware movingHardware = {
	&motorSystem,
	&motorX,
	&motorY,
	&motorZ,
	&motorYaw
};

static PickingHardware pickingHardware = {
	{&valve0},
	&pump,
	{&pressureSensor0}
};

static PlacingHardware placingHardware = {
	{&valve0},
	&pump,
	{&pressureSensor0}
};

static ValveHardware valveHardware = {
	{&valve0}
};

static PumpHardware pumpHardware = {
	&pump
};

static DataHandler dataHandler(&dataHandlerHw, &commandHandler);
static Controller controller(&commandHandler, &dataHandler);
static CommunicationHandler communicationHandler(&Serial);
static void resetAllCommandsCallback();
static void initializeHardware();
static void registerCommands();
static void communicationLoop(void* pvParameters);
static void controlLoop(void* pvParameters);
static void pressureUpdateLoop(void* pvParameters);

struct PressureTaskContext
{
	PressureSensor* pressureSensor[MAX_TOOLHEAD];
};

static PressureTaskContext pressureTaskContext = {
	{&pressureSensor0}
};

static void resetAllCommandsCallback()
{
	pump.off();
	valve0.off();
}

static void initializeHardware()
{
	motorX.setEnablePin(PIN_DX_EN);
	motorY.setEnablePin(PIN_DY_EN);
	motorZ.setEnablePin(PIN_DZ_EN);
	motorYaw.setEnablePin(PIN_DYAW_EN);

	motorX.setPinsInverted(true, false, true);
	motorY.setPinsInverted(true, false, true);
	motorZ.setPinsInverted(false, false, true);
	motorYaw.setPinsInverted(false, false, true);

	motorX.enableOutputs();
	motorY.enableOutputs();
	motorZ.enableOutputs();
	motorYaw.enableOutputs();

	motorSystem.addStepper(motorX);
	motorSystem.addStepper(motorY);
	motorSystem.addStepper(motorZ);
	motorSystem.addStepper(motorYaw);

	pressureSensor0.init();
}

static void registerCommands()
{
	static StopCommand stopCommand(&resetAllCommandsCallback);
	static PauseCommand pauseCommand;
	static MoveCommand moveCommand(&movingHardware);
	static PickCommand pickCommand(&pickingHardware);
	static PlaceCommand placeCommand(&placingHardware);
	static HomeCommand homeCommand(&homingHardware);
	static ValveCommand valveCommand(&valveHardware);
	static PumpCommand pumpCommand(&pumpHardware);

	if (!commandHandler.registerCommand(&stopCommand) ||
		!commandHandler.registerCommand(&pauseCommand) ||
		!commandHandler.registerCommand(&moveCommand) ||
		!commandHandler.registerCommand(&pickCommand) ||
		!commandHandler.registerCommand(&placeCommand) ||
		!commandHandler.registerCommand(&homeCommand) ||
		!commandHandler.registerCommand(&valveCommand) ||
		!commandHandler.registerCommand(&pumpCommand))
	{
		while (true)
		{
			vTaskDelay(pdMS_TO_TICKS(1000));
		}
	}
}

static void communicationLoop(void* pvParameters)
{
	(void)pvParameters;
	uint8_t payload[MAX_PAYLOAD_SIZE] = {};

	while (true)
	{
		ComHeader header;
		if(communicationHandler.readHeader(header))
		{
			if(communicationHandler.readPayload(payload, header.payloadSize, header.checkSum))
			{
				commandHandler.setCurrentCommand(payload, header.payloadSize);
			}
		}
		else
		{
			vTaskDelay(COMMUNICATION_IDLE_DELAY);
		}

		vTaskDelay(COMMUNICATION_DELAY);
		dataModel_t info = dataHandler.getInfo();
		communicationHandler.write(reinterpret_cast<uint8_t*>(&info), sizeof(info));
	}
}

static void controlLoop(void* pvParameters)
{
	Controller* localController = static_cast<Controller*>(pvParameters);

	while (true)
	{
		if (localController != nullptr)
		{
			localController->update();
		}
	}
}

static void pressureUpdateLoop(void* pvParameters)
{
	PressureTaskContext* context = static_cast<PressureTaskContext*>(pvParameters);

	while (true)
	{
		if (context != nullptr)
		{
			for (uint8_t i = 0; i < MAX_TOOLHEAD; ++i)
			{
				if (context->pressureSensor[i] != nullptr)
				{
					context->pressureSensor[i]->update();
				}
			}
		}

		vTaskDelay(PRESSURE_LOOP_DELAY);
	}
}
}

void setup()
{
	Serial.begin(SERIAL_BAUD_RATE);
	delay(SERIAL_STARTUP_DELAY_MS);
	while (!Serial)
	{
		delay(10);
	}

	initializeHardware();
	registerCommands();

		xTaskCreatePinnedToCore(communicationLoop, "communicationTask", COMMUNICATION_TASK_STACK, &controller, 1, nullptr, 0);
		xTaskCreatePinnedToCore(pressureUpdateLoop, "pressureTask", PRESSURE_TASK_STACK, &pressureTaskContext, 2, nullptr, 0);
		xTaskCreatePinnedToCore(controlLoop, "controlTask", CONTROL_TASK_STACK, &controller, 1, nullptr, 1);
}

void loop()
{
}

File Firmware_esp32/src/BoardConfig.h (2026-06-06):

/**
 * @file boardconfig.h
 * @author PickusAndPlacus
 * @brief Hardware abstraction layer defining GPIO pin assignments.
 * @version 1.0
 * @date 17/04/2026
 */

#ifndef BOARDCONFIG_H
#define BOARDCONFIG_H

// --- Stepper motor pins ---
#define PIN_DX_DIR 6        /// Direction pin for X-axis stepper (Driver DX)
#define PIN_DX_STEP 7       /// Step pulse pin for X-axis stepper
#define PIN_DX_EN 15        /// Enable pin for X-axis stepper (Active LOW)

#define PIN_DY_DIR 16       /// Direction pin for Y-axis stepper (Driver DY)
#define PIN_DY_STEP 17      /// Step pulse pin for Y-axis stepper
#define PIN_DY_EN 18        /// Enable pin for Y-axis stepper (Active LOW)

#define PIN_DZ_DIR 3        /// Direction pin for Z-axis stepper (Driver DZ)
#define PIN_DZ_STEP 46      /// Step pulse pin for Z-axis stepper
#define PIN_DZ_EN 11        /// Enable pin for Z-axis stepper (Active LOW)

#define PIN_DYAW_DIR 12     /// Direction pin for YAW-axis stepper (Driver DYAW)
#define PIN_DYAW_STEP 13    /// Step pulse pin for YAW-axis stepper
#define PIN_DYAW_EN 14      /// Enable pin for YAW-axis stepper (Active LOW)

// --- Switches ---
#define PIN_PUMP 5          /// Vacuum pump pin
#define PIN_VALVE 4         /// Solenoid valve pin
#define PIN_LIMSWITCH_X 35  /// Limit switch pin for X-axis origin
#define PIN_LIMSWITCH_Y 36  /// Limit switch pin for Y-axis origin
#define PIN_LIMSWITCH_Z 37  /// Limit switch pin for Z-axis origin

// --- Communication --- //Currently not used but are for expension
// #define PIN_I2C_SDA 8
// #define PIN_I2C_SCA 9
// #define PIN_CANIC_TX 47
// #define PIN_CANIC_RX 48

// --- Sensors ---
#define PIN_PSENSOR_CLK 2   /// Pressure sensor clock pin
#define PIN_PSENSOR_DATA 1  /// Pressure sensor output pin

// --- Hardware counts / limits ---
#define MAX_TOOLHEAD 1      // Number of toolheads supported

#endif

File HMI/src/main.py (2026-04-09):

from file_interpreter import FileInterpreter
from storage import Storage
from slicer import Slicer
from data import *
from gui.interface import Interface
from PyQt5 import QtWidgets
from PyQt5.QtWidgets import QApplication
import sys



if __name__ == "__main__":
    print("Starting Program")

    try : 
        app = QApplication(sys.argv)
        window = Interface()
        window.show()
        app.exec()



    except Exception as e : 
        print(f"An error occured during the execution of the main program : {e}")

    print ("End of program")
    

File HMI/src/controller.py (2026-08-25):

import threading
import time
from typing import List

from command_interface import CommandInterface, CommandPacket, PauseCommand, StopCommand
from comm_parser import CommLogFilter, CommParser
from communication import Communication
from command_dispatcher import CommandDispatcher
from homing_service import HomingService
from machine_telemetry_decoder import MachineTelemetryDecoder
from pnp_state_machine import PnPStateMachine
from data import ControllerState, MachineState, Position, TransitionRequest, MAX_TOOLHEAD
from storage import Storage


class Controller:
    """Facade over command queueing, state transitions, telemetry, and homing."""

    def __init__(self):
        if hasattr(self, "initialized"):
            return
        self.initialized = True

        self._storage = Storage()
        self._com = None
        self.commandInWaiting: List[CommandPacket] = []
        self._commands = []
        self._lastCommand: CommandPacket | None = None
        self._controllerState = ControllerState.IDLE
        self._latestCommandId = 0
        self._latestCommandNumber = 0
        self._latestMachineState = MachineState.READY
        self._latestMachinePosition = Position(0, 0, 0, 0)
        self._latestMachinePressure: float = 0.0
        self._latestMachinePressures: list[float] = [0.0 for _ in range(MAX_TOOLHEAD)]
        self._latestMachineValveStates: list[bool] = [False for _ in range(MAX_TOOLHEAD)]
        self._latestMachinePumpState: bool = False
        self._commandInterface = CommandInterface()
        self._commParser = CommParser()
        self._closeEvent = threading.Event()
        self._comThread = None
        self._controllerRequestTransitionField = 0
        self._timeSinceLastResponse: float = -1
        self._missedResponses = 0
        self._connected = False
        self._stopRequested = False
        self._commandParsingEnabled = True
        self.mutex = threading.Lock()

        self._commandDispatcher = CommandDispatcher(self)
        self._stateMachine = PnPStateMachine(self, self._commandDispatcher)
        self._telemetryDecoder = MachineTelemetryDecoder(self)
        self._homingService = HomingService(self)

        self.homed = False
        self.blocked = False

    def __new__(cls):
        if not hasattr(cls, "instance"):
            cls.instance = super(Controller, cls).__new__(cls)
        return cls.instance

    def queueCommand(self, command: CommandPacket):
        with self.mutex:
            self._commands.append(command)

    def queueCommands(self, commands: list[CommandPacket]):
        with self.mutex:
            self._commands.extend(commands)

    def requestTransition(self, transition: TransitionRequest):
        self._stateMachine.requestTransition(transition)

    def connectionToMachine(self, comPort: str, baudrate: int):
        self._timeSinceLastResponse = time.time() * 1000
        self._com = Communication(comPort, baudrate)
        self._com.open()
        self._commParser.setEnabled(self._commandParsingEnabled)
        self._closeEvent = threading.Event()
        self._comThread = threading.Thread(target=self._controlLoop)
        self._comThread.start()

    def disconnectionFromMachine(self):
        if self._com is not None:
            self._com.close()
            self._com = None

        if self._comThread is not None:
            self._closeEvent.set()
            self._comThread.join()
            self._comThread = None

        self._connected = False

    def isConnected(self) -> bool:
        return self._connected

    def isPortOpen(self):
        return self._comThread is not None

    def setCommandParsingEnabled(self, enabled: bool):
        self._commandParsingEnabled = enabled
        self._commParser.setEnabled(enabled)

    def isCommandParsingEnabled(self) -> bool:
        return self._commandParsingEnabled

    def addCommLogListener(self, listener):
        self._commParser.addListener(listener)

    def updateCommLogListenerFilter(self, listener, log_filter: CommLogFilter | None):
        self._commParser.updateListenerFilter(listener, log_filter)

    def removeCommLogListener(self, listener):
        self._commParser.removeListener(listener)

    def start_pnp(self):
        if self.blocked:
            return
        self._stateMachine.requestTransition(TransitionRequest.TO_RUNNING)
        self._commandDispatcher.queueCommands(self.commandInWaiting)

    def goHome(self, endingFunction):
        if self.blocked:
            return
        if not self.isConnected():
            return
        self._homingService.start(endingFunction)

    def getMachineState(self) -> MachineState:
        with self.mutex:
            state = self._latestMachineState
        return state
    
    def getMachineCommandNumber(self) -> int:
        with self.mutex:
            commandNumber = self._latestCommandNumber
        return commandNumber
    
    def getGripperPosition(self) -> Position:
        with self.mutex:
            position = self._latestMachinePosition
        return position
    
    def getMachinePressure(self) -> float:
        with self.mutex:
            pressure = self._latestMachinePressure
        return pressure

    def getMachinePressures(self) -> list[float]:
        with self.mutex:
            pressures = list(self._latestMachinePressures)
        return pressures

    def getMachineValveStates(self) -> list[bool]:
        with self.mutex:
            valves = list(self._latestMachineValveStates)
        return valves

    def getMachinePumpState(self) -> bool:
        with self.mutex:
            pump = self._latestMachinePumpState
        return pump

    def getLatestCommandId(self) -> int:
        with self.mutex:
            commandId = self._latestCommandId
        return commandId

    def getControllerState(self) -> ControllerState:
        with self.mutex:
            controllerState = self._controllerState
        return controllerState
    
    def getLastCommand(self) -> CommandPacket:
        with self.mutex:
            lastCommand = self._lastCommand
        return lastCommand

    def setPnpCommands(self, commands: list[CommandPacket]):
        if self.blocked:
            return
        self.commandInWaiting = commands

    def pausePnP(self):
        self.requestTransition(TransitionRequest.TO_PAUSE)

    def toggleRunningMode(self):
        self.requestTransition(TransitionRequest.TO_RUNNING)

    def toggleManualMode(self):
        self.requestTransition(TransitionRequest.TO_MANUAL)

    def toggleIDLEMode(self):
        self._commandDispatcher.clearCommands()
        self.requestTransition(TransitionRequest.TO_IDLE)

    def stopPnP(self):
        if self.blocked:
            return
        self._commandDispatcher.clearCommands()
        self._commandDispatcher.sendCommand(StopCommand())
        self.requestTransition(TransitionRequest.TO_IDLE)

    def continuePnP(self):
        self.requestTransition(TransitionRequest.TO_RUNNING)
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

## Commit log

2026-01-16 kicad project creation
    [circuitPNP.kicad_pcb, circuitPNP.kicad_sch]
2026-01-16 blue print for test PCB
    [PCB_test.kicad_pcb, PCB_test.kicad_sch]
2026-01-16 add drawio schematic
2026-01-16 wip and gitignore update
    [circuitPNP.kicad_sch]
2026-01-16 Calibration and mounting hole added to test PCB
    [PCB_test.kicad_pcb, PCB_test.kicad_sch]
2026-01-17 wip, most part are on the circuit, mssing connection
    [circuitPNP.kicad_sch]
2026-01-17 gitignore update and circuit mostly done, only missing bulck cap value
    [circuitPNP.kicad_sch]
2026-01-17 Name and logo added to test PCB
    [PCB_test.kicad_pcb]
2026-01-17 forgot to save file lmao
    [PCB_test.kicad_pcb]
2026-01-18 only bulck cap value missing, all footprint are selected for a pcb
    [circuitPNP.kicad_pcb, circuitPNP.kicad_sch]
2026-01-19 circuit done
    [circuitPNP.kicad_sch]
2026-01-20 pcb wip
    [circuitPNP.kicad_pcb, circuitPNP.kicad_sch]
2026-01-21 test and images now on correct layer
    [PCB_test.kicad_pcb]
2026-01-21 edge cut is clean
    [PCB_test.kicad_pcb]
2026-01-21 reference hole added
    [PCB_test.kicad_pcb, PCB_test.kicad_sch]
2026-01-21 fixed error on the ground layer
    [PCB_test.kicad_pcb]
2026-01-21 Position of ref now aligns on board grid
    [PCB_test.kicad_pcb, PCB_test.kicad_sch]
2026-01-21 wip pcb
    [circuitPNP.kicad_pcb, circuitPNP.kicad_sch]
2026-01-23 pcb done, wainting for circuit testing
    [circuitPNP.kicad_pcb, circuitPNP.kicad_sch]
2026-01-23 missed that
    [circuitPNP.kicad_pcb]
2026-01-23 pull down on gate for mosfet
    [circuitPNP.kicad_pcb]
2026-01-26 fabricationFile for v1
    [circuitPNP.kicad_pcb, circuitPNP.kicad_sch]
2026-01-27 Fonction moteur
    Premiere fonction de test
2026-01-28 fixed oversight with delta pos on the storage with the slicer
    [slicer.py]
2026-02-01 File structure and multistepper
    Header file added and 2 motors sync control
2026-02-03 Board config and motor array
    Pins in board config and motor array for moveTo
2026-02-10 pressure sensor class working
2026-02-16 test code for MOVE in loop, target{} components in long format and corrected stepper instanciation
    Controller testing and debugging
    [BoardConfig.h, main.cpp]
2026-02-23 some bug fix, board config update, platformio build flag and demo code in main
    [BoardConfig.h, main.cpp]
2026-02-25 missing function prototype
2026-02-26 Revert "Merge branch 'Feature/communicationEsp32' of https://github.com/GabrielD98/PickUS_and_PlacUS into Feature/communicationEsp32"
    This reverts commit a8f47d028d8c48deba7b62e96769ae00835378e1, reversing
    changes made to 508c28567d246e0c2429fbe5e21b49e79fbfce82.
    [communication.py, controller.py, main.cpp]
2026-03-02 limit switch
2026-03-03 Global calibration added
2026-03-03 complete ready, moving, and homing state. only missing picking and placing.
2026-03-04 Fixed buttons enabling order to be more intuitive
2026-03-04 Mosfet class, pick and place states and functions
2026-03-10 fix com delay (add ms to tick conversion)
    [main.cpp]
2026-03-11 homing added
2026-03-11 Physical limitations correction, rescaling in Z
    [main.cpp]
2026-03-11 homing intergration tested
2026-03-17 fixed storage bug with component position
    [data.py, slicer.py, storage.py]
2026-03-18 fixed stringed position bug
    [data.py]
2026-03-18 Geometry test fixed
    Fix on the yaw for the geometry test
    [main.cpp]
2026-03-18 fix z axis not moving
    [data.py]
2026-03-20 ProperReadMe and elec file cleanup
    [PNP_MOBO_V1.kicad_pcb, PNP_MOBO_V1.kicad_sch, PNP_TEST_CIRCUIT_V1.kicad_pcb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]
2026-03-20 fixed display and slicing issue
    [slicer.py]
2026-03-20 fixe picking and placing issue
    [data.py, slicer.py]
2026-03-21 go to position now more intuitive
    if a user entered a faulty input in the entry, the entry value will be set to the current position insted of refusing the input
2026-03-22 fix pump never closing
2026-03-25 fixed slice position issues
    [data.py, slicer.py]
2026-03-25 switch x and y axis on PnP
2026-03-25 fix x,y swap, and change threshold for pump
2026-03-25 fixed start pause continue features
    doesnt work for homing
    [controller.py]
2026-03-25 Commentaries, Geometry test correction
    Commentaries on Mosfet and Limitswitch.
2026-03-27 z axis change
2026-03-27 modify test for z axis change
2026-03-27 calibration can now be loaded from JSON file
2026-03-27 limit switch bug fix, change threshold for pressure sensor
2026-03-31 Calibrations can now be saved
2026-03-31 Now UI scan for ESP32 port only
2026-03-31 removed clamping for yaw
2026-03-31 Calibration window now centered on opening
2026-03-31 Homing can now occured outside of main UI (bug fixed)
2026-03-31 Error msg window added
    [utils.py]
2026-03-31 Fixed layout of calibrations
2026-04-01 ESP code documentation WIP, position struct differentiation between step and cartesian
    TestCom and pressureSensor remaining to do document
2026-04-03 small change in board config
2026-04-03 limit switch doc review
2026-04-03 pressure sensore doc
2026-04-03 add stencil for test pcb and update elec documentation
    [STENCIL.3mf]
2026-04-05 path fix for julius
    [data.py]
2026-04-09 fixed calibration saves with non-existent file
2026-04-09 merged tested and fixed jog spamming issue
    [controller.py]
2026-04-09 fixed stop and ending sequence
    [controller.py]
2026-04-10 documentation for the calibration window
2026-04-16 Completed Instructions and STL_Files
    [90DegreesJoint.stl, Adaptor_RailY_Extrude_Inferior.stl, Adaptor_RailY_Extrude_Superior_Idle.stl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]
2026-04-26 refactor pressure to add a getter and an update function
2026-04-26 add mutex to prevent setpayload to write while run or prepare is called
    [HomeCommand.cpp, MoveCommand.cpp]
2026-05-18 fix broken save calib button
2026-05-24 remove reset in command
    [HomeCommand.cpp, MoveCommand.cpp]
2026-05-24 add pressure to hmi
2026-05-25 add setting window, debug window and manual control of valve and pump
2026-05-26 add way to filter log ex: 1,2 will show pause and move cmd
2026-05-27 modify python test to run at the same time as esp32 test
2026-05-27 setting update and remove trace from debug window
2026-06-01 wip in circuit, moved drive and sensor in new sheet, add global sig
    [Drive.kicad_sch, PNP_MOBO_V2.kicad_pcb, PNP_MOBO_V2.kicad_sch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]
2026-06-02 circuit mostly done!
    [PNP_MOBO_V2.kicad_sch]
2026-06-06 wip pcbv2
    [Drive.kicad_sch, PNP_MOBO_V2.kicad_pcb, PNP_MOBO_V2.kicad_sch]
2026-06-06 final push of the rework, fix homing test, fix multiple start not working
    [home_command_test.cpp, pnp_state_machine.py, slicer.py]
2026-06-16 rooting done, only last check and test missing
    [PNP_MOBO_V2.kicad_pcb, PNP_MOBO_V2.kicad_sch]
2026-06-17 add i bom and fabrication file
    [PNP_MOBO_V2.kicad_pcb, PNP_MOBO_V2.kicad_sch]
2026-06-21 fix: last change before order
    [PNP_MOBO_V2.kicad_pcb, PNP_MOBO_V2.kicad_sch]
2026-06-25 fix: wrong connection on power inpt
    [PNP_MOBO_V2.kicad_sch]
2026-09-22 fix: dir inversion for motor x and y
    [main.cpp]
